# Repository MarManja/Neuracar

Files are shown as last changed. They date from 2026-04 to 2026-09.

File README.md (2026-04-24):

# Neuracar

Este es un proyecto de navegación autónoma basado en ROS 2.

## Estructura
- **neuracar_bringup**: Archivos de lanzamiento y configuración.
- **neuracar_sensors**: Nodos de sensores (IMU, encoder, LiDAR, cámara).
- **neuracar_control**: Nodos de control para tracción, dirección y vehículo.

## Dependencias externas
- **RPLidar A2M12**: LiDAR.
- **Intel RealSense D415**: Cámara.

## Instalación
```bash
git clone https://github.com/tu_usuario/Neuracar.git
cd Neuracar
vcs import src < neuracar.repos
rosdep install --from-paths src --ignore-src -r -y
colcon build
source install/setup.bash

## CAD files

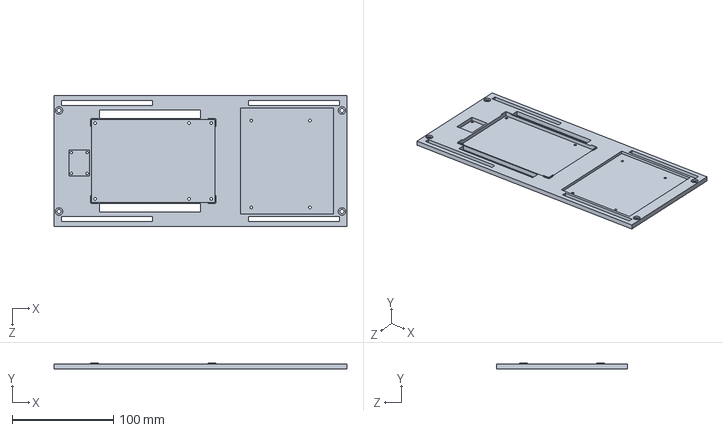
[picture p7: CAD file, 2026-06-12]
mechanical/sldprt/base PLA.SLDPRT
290.0 x 6.00 x 130.0 mm

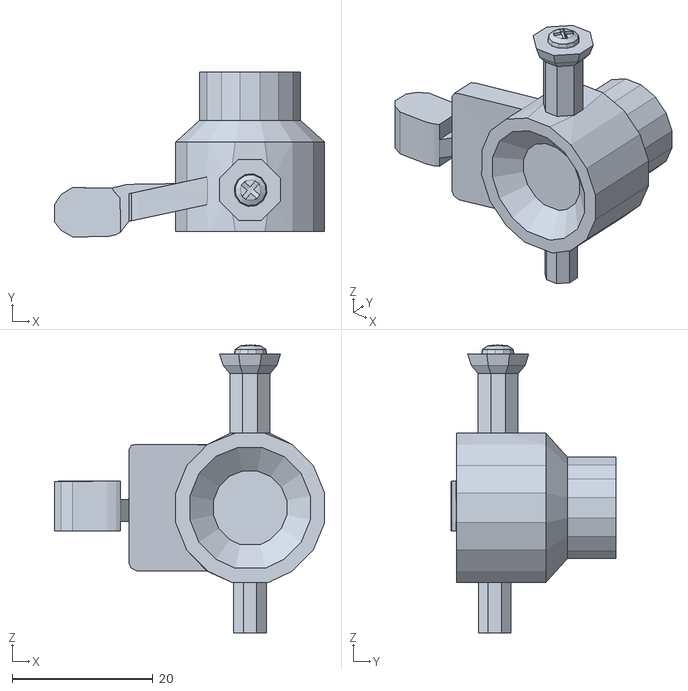
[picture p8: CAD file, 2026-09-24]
src/neuracar_description/meshes/SteeringHubL.stl
38.4 x 23.4 x 40.9

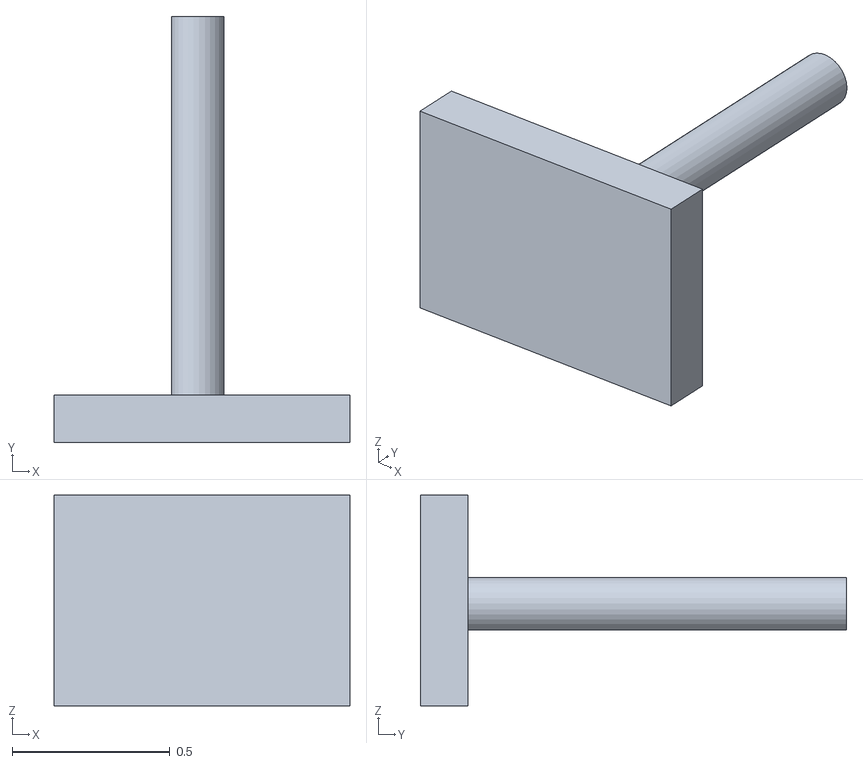
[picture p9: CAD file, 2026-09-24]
src/neuracar_gazebo/models/sign_board_30/meshes/sign_stand.obj
0.937 x 1.35 x 0.668

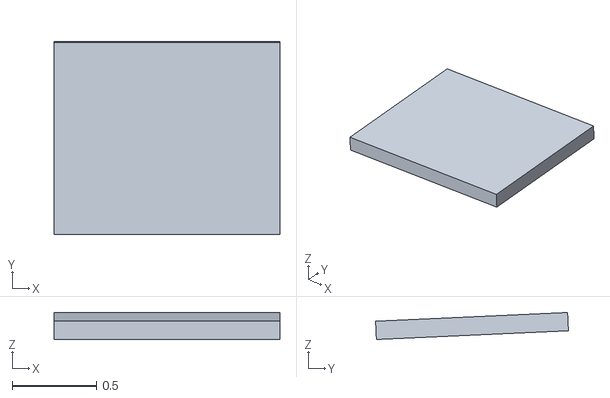
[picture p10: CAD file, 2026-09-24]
src/neuracar_gazebo/models/sign_board_left_turn/meshes/sign_board.obj
1.34 x 1.14 x 0.16

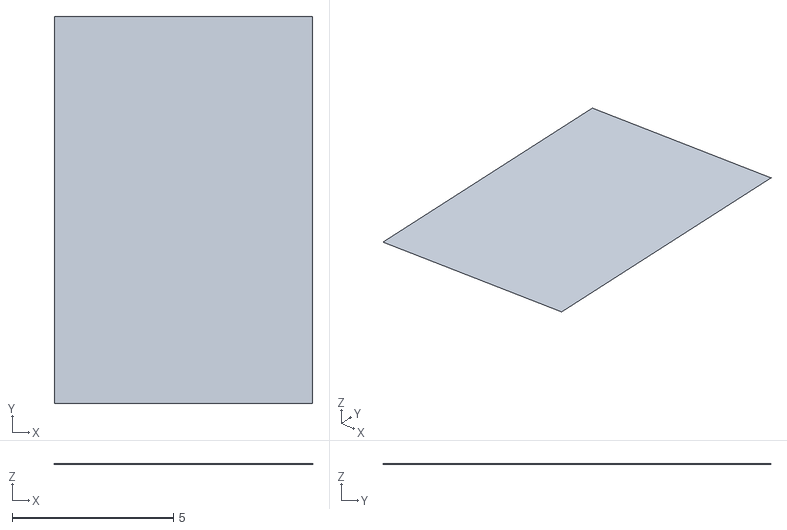
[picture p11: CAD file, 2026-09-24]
src/neuracar_gazebo/models/tmr_track/meshes/automodelcar_tmr.obj
8.00 x 12.0 x 0.002

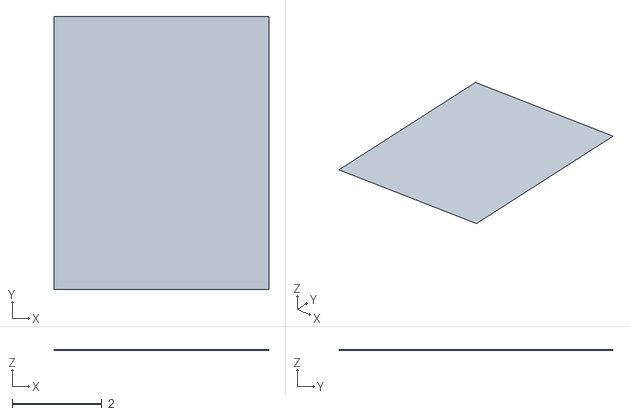
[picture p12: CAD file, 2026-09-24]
src/neuracar_gazebo/models/track/meshes/qcar_track.obj
4.80 x 6.10 x 0.0025

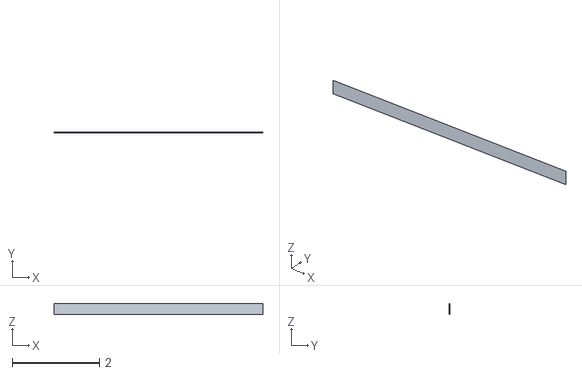
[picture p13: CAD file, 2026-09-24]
src/neuracar_gazebo/models/wall_4_8x0_25/meshes/wood_wall_short.obj
4.80 x 0.0025 x 0.25

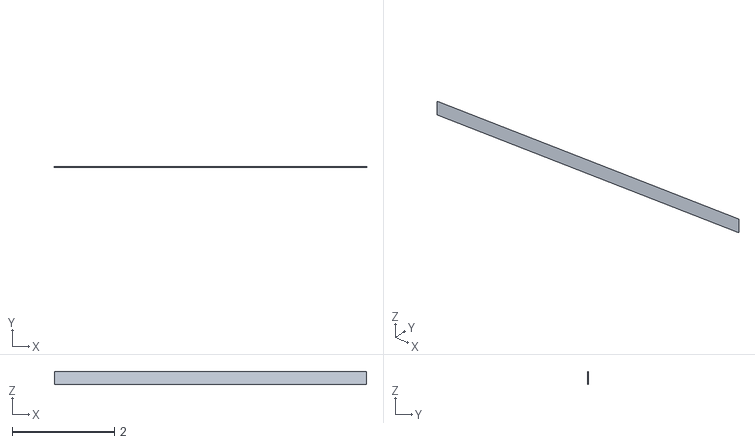
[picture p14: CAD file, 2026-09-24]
src/neuracar_gazebo/models/wall_6_1x0_25/meshes/wood_wall_long.obj
6.10 x 0.0025 x 0.25

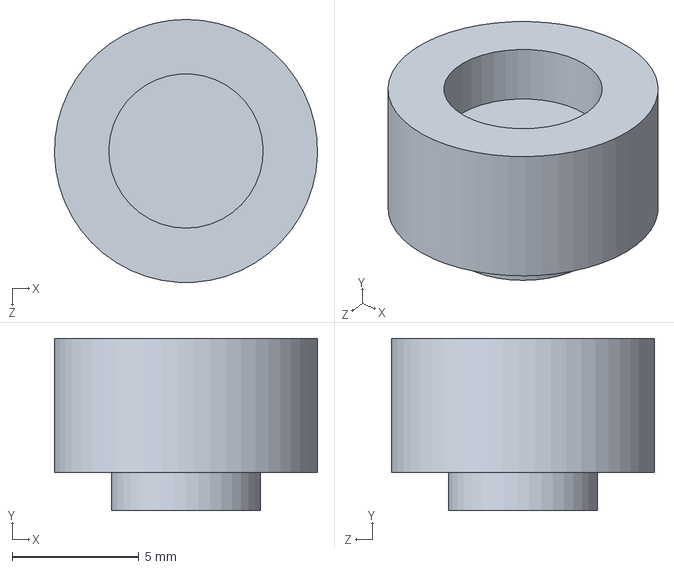
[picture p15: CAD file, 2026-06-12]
mechanical/sldprt/iman.SLDPRT
10.4 x 6.80 x 10.4 mm

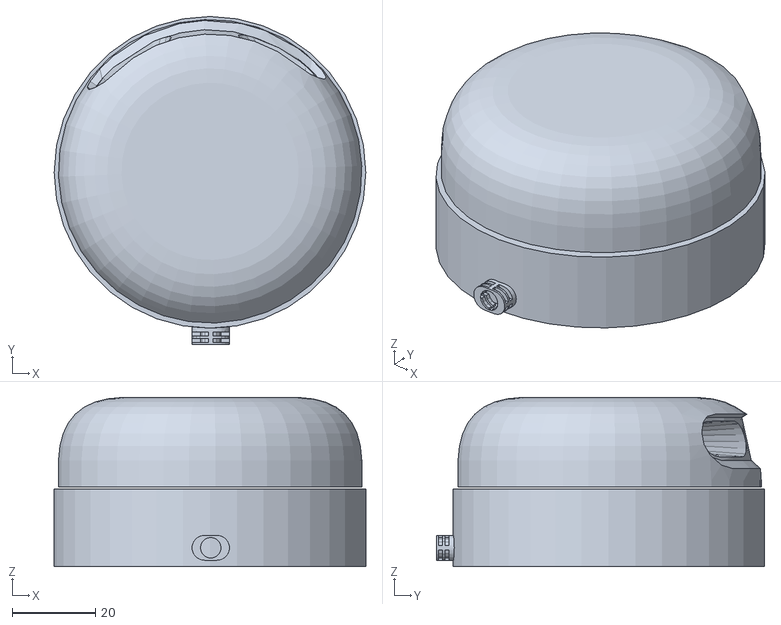
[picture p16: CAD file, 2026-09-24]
src/neuracar_description/meshes/Lidar_A3.stl
75.0 x 78.9 x 40.6

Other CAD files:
src/neuracar_gazebo/models/sign_board_stop/meshes/sign_board.obj
src/neuracar_gazebo/models/sign_board_30/meshes/sign_board.obj
src/neuracar_gazebo/models/sign_board_60/meshes/sign_board.obj
src/neuracar_gazebo/models/sign_board_90/meshes/sign_board.obj
docs/planos/Acrilico.SLDDRW
docs/planos/Soporte Encoder.SLDDRW
docs/planos/Soporte Iman.SLDDRW
docs/planos/inferior.SLDDRW
docs/planos/soporte bateria 2.SLDDRW
docs/planos/soporte bateria.SLDDRW
docs/planos/superior.SLDDRW
mechanical/sldprt/base acrilico.SLDPRT
mechanical/sldprt/bateria Lipo.SLDPRT
mechanical/sldprt/bateria NP-F.SLDPRT
mechanical/sldprt/buck-boost.SLDPRT
mechanical/sldprt/encoder.SLDPRT
mechanical/sldprt/superior.SLDPRT
mechanical/stl/base PLA.STL
mechanical/stl/base acrilico.STL
mechanical/stl/bateria Lipo.STL
mechanical/stl/bateria NP -F.STL
mechanical/stl/buck - boost.STL
mechanical/stl/superior.STL
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

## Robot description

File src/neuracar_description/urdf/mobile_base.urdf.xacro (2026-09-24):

<?xml version="1.0"?>

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
<robot name="Neuracar" xmlns:xacro="http://www.ros.org/wiki/xacro">
  <xacro:macro name="Neuracar" params="parent prefix *origin">
    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
    <xacro:include filename="$(find neuracar_description)/urdf/common_properties.xacro" />

    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
    <xacro:property name="degrees_30" value="0.523599"/>
    <xacro:property name="degrees_45" value="0.785398163"/>
    <xacro:property name="degrees_90" value="1.57079633"/>

    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
    <xacro:property name="chassis_length" value="0.425"/>
    <xacro:property name="chassis_width" value="0.192"/>
    <xacro:property name="chassis_height" value="0.182"/>
    <xacro:property name="chassis_mass" value="2.552"/>

  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
    <xacro:property name="hub_dia" value="0.015"/>
    <xacro:property name="tire_dia" value="0.053"/>
    <xacro:property name="tire_width" value="0.025"/>
    <xacro:property name="hex_hub_depth" value="0.018"/>
    <xacro:property name="wheel_mass" value="0.035"/>
  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
    <xacro:property name="wheelbase" value="0.265"/>
    <xacro:property name="hex_hub_dist" value="0.285"/>
    <xacro:property name="axle_length" value="0.025"/>
    <xacro:property name="axle_eff_limit" value="5.12766"/>
    <xacro:property name="axle_vel_limit" value="244.8696"/>
    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
    <xacro:property name="servo_stall_torque" value="0.5649"/>
    <xacro:property name="servo_no_load_speed" value="4.553"/>

    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
    <xacro:property name="ctrl_period" value="0.01"/>


    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
    <xacro:macro name="null_inertial">
      <inertial>
        <origin rpy="0 0 0" xyz="0 0 0"/>
        <mass value="0.001"/>
        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
      </inertial>
    </xacro:macro>

    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
    <xacro:macro name="solid_cuboid_inertial" params="width depth height mass *origin">
      <inertial>
        <xacro:insert_block name="origin"/>
        <mass value="${mass}"/>
        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
      </inertial>
    </xacro:macro>

    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
    <xacro:macro name="thick_walled_tube_inertial" params="inner_rad outer_rad height mass">
      <inertial>
        <mass value="${mass}"/>
        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
      </inertial>
    </xacro:macro>

    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

   <link name="base_footprint" />

    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
    <link name="base_link">
      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

      <xacro:solid_cuboid_inertial width="${chassis_length}" depth="${chassis_width}" height="${chassis_height}" mass="${chassis_mass}">
        <origin xyz="0 0 0"/>
      </xacro:solid_cuboid_inertial>
      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

    </link>

  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
    <joint name="base_footprint_to_chasis" type="fixed">
      <parent link="base_footprint"/>
      <child link="base_link"/>
    </joint>

    <joint name="body_lidar_joint" type="fixed">
      <parent link="base_link"/>
      <child link="lidar_base"/>
      <origin rpy="0 0 0" xyz="0.0227 -0.00145 0.14352"/>
      <axis xyz="0 0 1"/>
      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
    </joint>
    <link name="lidar_base">
        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
        <inertial>
          <origin rpy="0 0 0" xyz="0 0 0"/>
          <mass value="0.1"/>
          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
        </inertial>
    </link>
    <link name="lidar"/>
    <joint name="lidar_base_to_optics_joint" type="fixed">
      <parent link="lidar_base"/>
      <child link="lidar"/>
      <origin xyz="0.0 0.0 0.031" rpy="0.0 0.0 0.0"/>
    </joint>

    <joint name="camera_rgb_joint" type="fixed">
      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
      <origin rpy="0 0.192 0" xyz="0.0914 -0.0015 0.14622"/>
      <parent link="base_link"/>
      <child link="camera_rgb"/>
    </joint>
    <link name="camera_rgb">
      <inertial>
        <mass value="0.0615752"/>
        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
      </inertial>
      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
    </link>

    <joint name="imu_joint" type="fixed">
        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
         <origin rpy="0 0 ${-pi/2.0}" xyz="0.1355 0.0015 0.094"/>
        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
        <parent link="base_link"/>
        <child link="imu"/>
    </joint>
    <link name="imu">
      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
      <xacro:box_inertia m="0.0025" l="0.0257" w="0.0205" h="0.0025" xyz="0 0 0" rpy="0 0 0"/>
    </link>

    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
    
    <joint name="left_front_position_joint" type="fixed">
      <parent link="base_link"/>
      <child link="left_steering_link"/>
      <origin rpy="0 0 0" xyz="0.12960 0.05590 0.03338"/>
      <axis xyz="0 0 1" />
    </joint>

    <link name="left_steering_link">
      <xacro:null_inertial/>
      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
    </link>
    
    <joint name="left_steering_joint" type="revolute">
      <parent link="left_steering_link"/>
      <child link="left_front_axle_carrier"/>
      <axis xyz = "0 0 1"/>
      <limit lower="-0.523599" upper="0.523599" effort="0.5649" velocity="4.553"/>
      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
    </joint>
    
    <link name="left_front_axle_carrier">
      <xacro:null_inertial/>
    </link>
    
    <joint name="left_front_axle" type="continuous">
      <parent link="left_front_axle_carrier"/>
      <child link="left_front_wheel"/>
      <axis xyz="0 -1 0"/>
      <origin rpy="0 0 3.14159"/>
      <limit effort="5.12766" velocity="244.8696"/>
      <dynamics damping="0.1" friction="0.1"/>
      <mimic joint="left_rear_axle" multiplier="1.0" offset="0"/>
    </joint>
    
    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
    <link name="left_front_wheel">
      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
      <xacro:thick_walled_tube_inertial inner_rad="${hub_dia / 2}" outer_rad="${tire_dia / 2}" height="${tire_width}" mass="${wheel_mass}"/>
    </link>

    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

    <link name="right_front_axle_carrier">
      <xacro:null_inertial/>
    </link>
    <joint name="right_front_axle" type="continuous">
      <parent link="right_front_axle_carrier"/>
      <child link="right_front_wheel"/>
      <axis xyz="0 1 0"/>
      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
      <limit effort="5.12766" velocity="244.8696"/>
      <dynamics damping="0.1" friction="0.1"/>
      <mimic joint="right_rear_axle" multiplier="1.0" offset="0"/>
    </joint>
    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
    <link name="right_front_wheel">
      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
      <xacro:thick_walled_tube_inertial inner_rad="${hub_dia / 2}" outer_rad="${tire_dia / 2}" height="${tire_width}" mass="${wheel_mass}"/>
    </link>

    <joint name="right_front_position_joint" type="fixed">
      <parent link="base_link"/>
      <child link="right_steering_link"/>
      <origin rpy="0 0 0" xyz="0.12960 -0.05590 0.03338"/>
    </joint>

    <link name="right_steering_link">
      <xacro:null_inertial/>
      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
    </link>

    <joint name="right_steering_joint" type="revolute">
      <parent link="right_steering_link"/>
      <child link="right_front_axle_carrier"/>
      <axis xyz = "0 0 1"/>
      <limit lower="-0.523599" upper="0.523599" effort="0.5649" velocity="4.553"/>
      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
    </joint>

    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
    <link name="left_rear_axle_carrier">
      <xacro:null_inertial/>
    </link>
    <joint name="left_rear_axle" type="continuous">
      <parent link="left_rear_axle_carrier"/>
      <child link="left_rear_wheel"/>
      <axis xyz="0 -1 0"/>
      <origin rpy="0 0 3.14159"/>
      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
      <dynamics damping="0.1" friction="0.1"/>
    </joint>
    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
    <link name="left_rear_wheel">
      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
      <xacro:thick_walled_tube_inertial inner_rad="${hub_dia / 2}" outer_rad="${tire_dia / 2}" height="${tire_width}" mass="${wheel_mass}"/>
    </link>

    <joint name="left_rear_position_joint" type="fixed">
      <parent link="base_link"/>
      <child link="left_rear_axle_carrier"/>
      <origin rpy="0 0 0" xyz="-0.12765 0.05610 0.03338"/>
    </joint>

  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

    <link name="right_rear_axle_carrier">
      <xacro:null_inertial/>
    </link>
    <joint name="right_rear_axle" type="continuous">
      <parent link="right_rear_axle_carrier"/>
      <child link="right_rear_wheel"/>
      <axis xyz="0 1 0"/>
      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
      <dynamics damping="0.1" friction="0.1"/>
    </joint>
    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
    <link name="right_rear_wheel">
      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
      <xacro:thick_walled_tube_inertial inner_rad="${hub_dia / 2}" outer_rad="${tire_dia / 2}" height="${tire_width}" mass="${wheel_mass}"/>
    </link>

    <joint name="right_rear_position_joint" type="fixed">
      <parent link="base_link"/>
      <child link="right_rear_axle_carrier"/>
      <origin rpy="0 0 0" xyz="-0.12765 -0.05610 0.03338"/>
    </joint>

    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
  
  </xacro:macro>

</robot>

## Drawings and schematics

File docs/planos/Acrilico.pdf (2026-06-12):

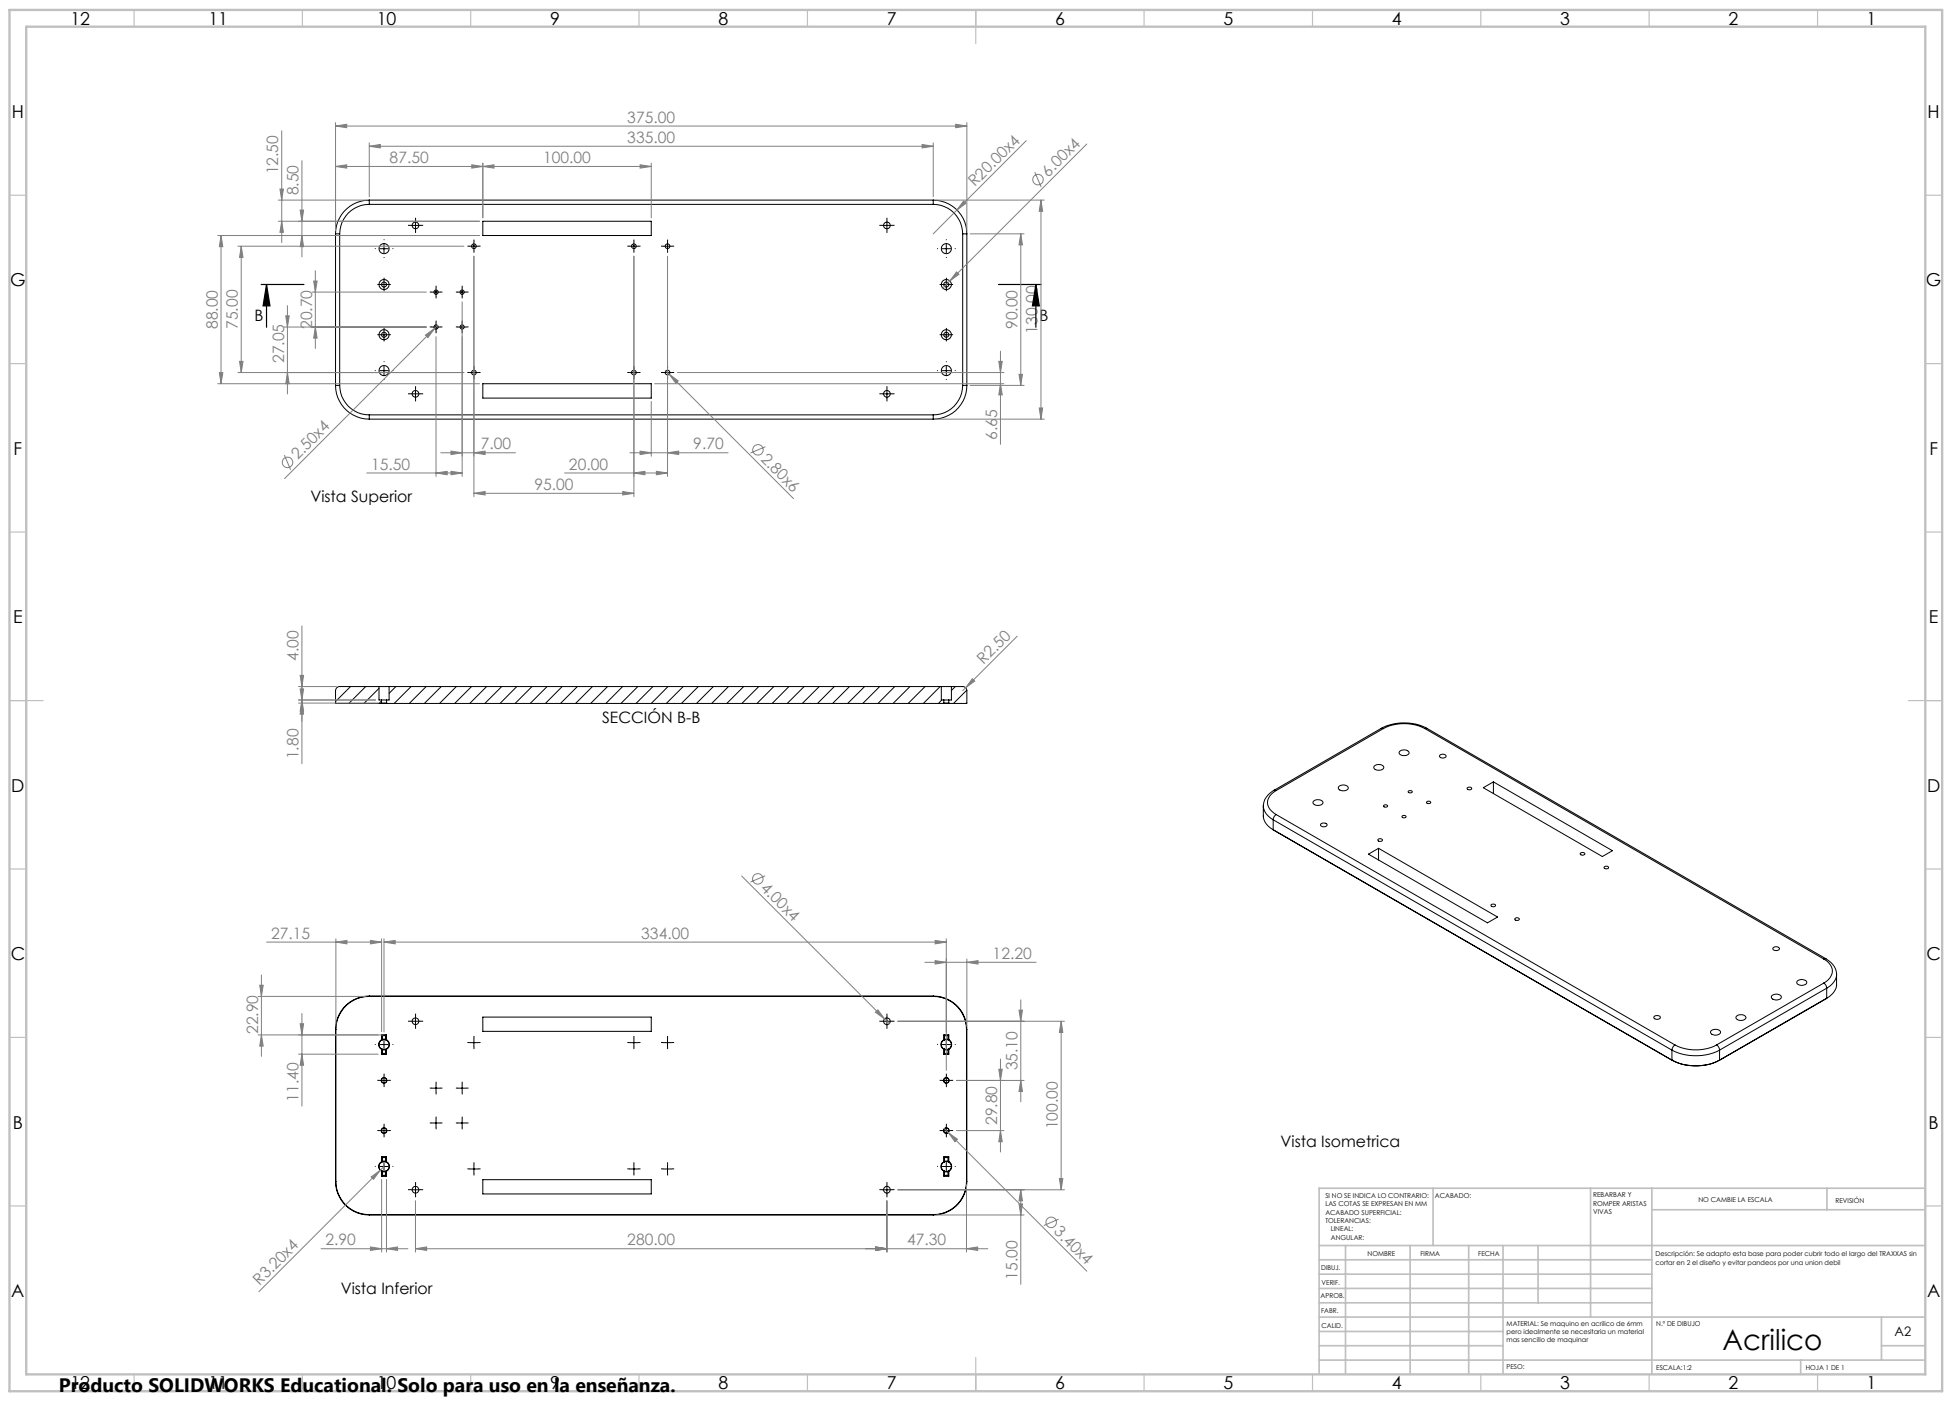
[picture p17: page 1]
Vista Superior; SECCIÓN B-B; Vista Inferior; Vista Isometrica; ACABADO:; REBARBAR Y; ROMPER ARISTAS; NO CAMBIE LA ESCALA; REVISIÓN; ESCALA:1:2; HOJA 1 DE 1

SI NO SE INDICA LO CONTRARIO:
LAS COTAS SE EXPRESAN EN MM
ACABADO SUPERFICIAL:
TOLERANCIAS:
LINEAL:
ANGULAR:

NOMBRE | FIRMA | FECHA | | | | Descripción: Se adapto esta base para poder cubrir todo el largo del TRAXXAS sin cortar en 2 el diseño y evitar pandeos por una union debil

DIBUJ.
VERIF.
APROB.
FABR.
CALID. | | | | MATERIAL: Se maquino en acrilico de 6mm pero idealmente se necesitaria un material mas sencillo de maquinar | N.º DE DIBUJO Acrilico | A2

Producto SOLIDWORKS Educational. Solo para uso en la enseñanza.

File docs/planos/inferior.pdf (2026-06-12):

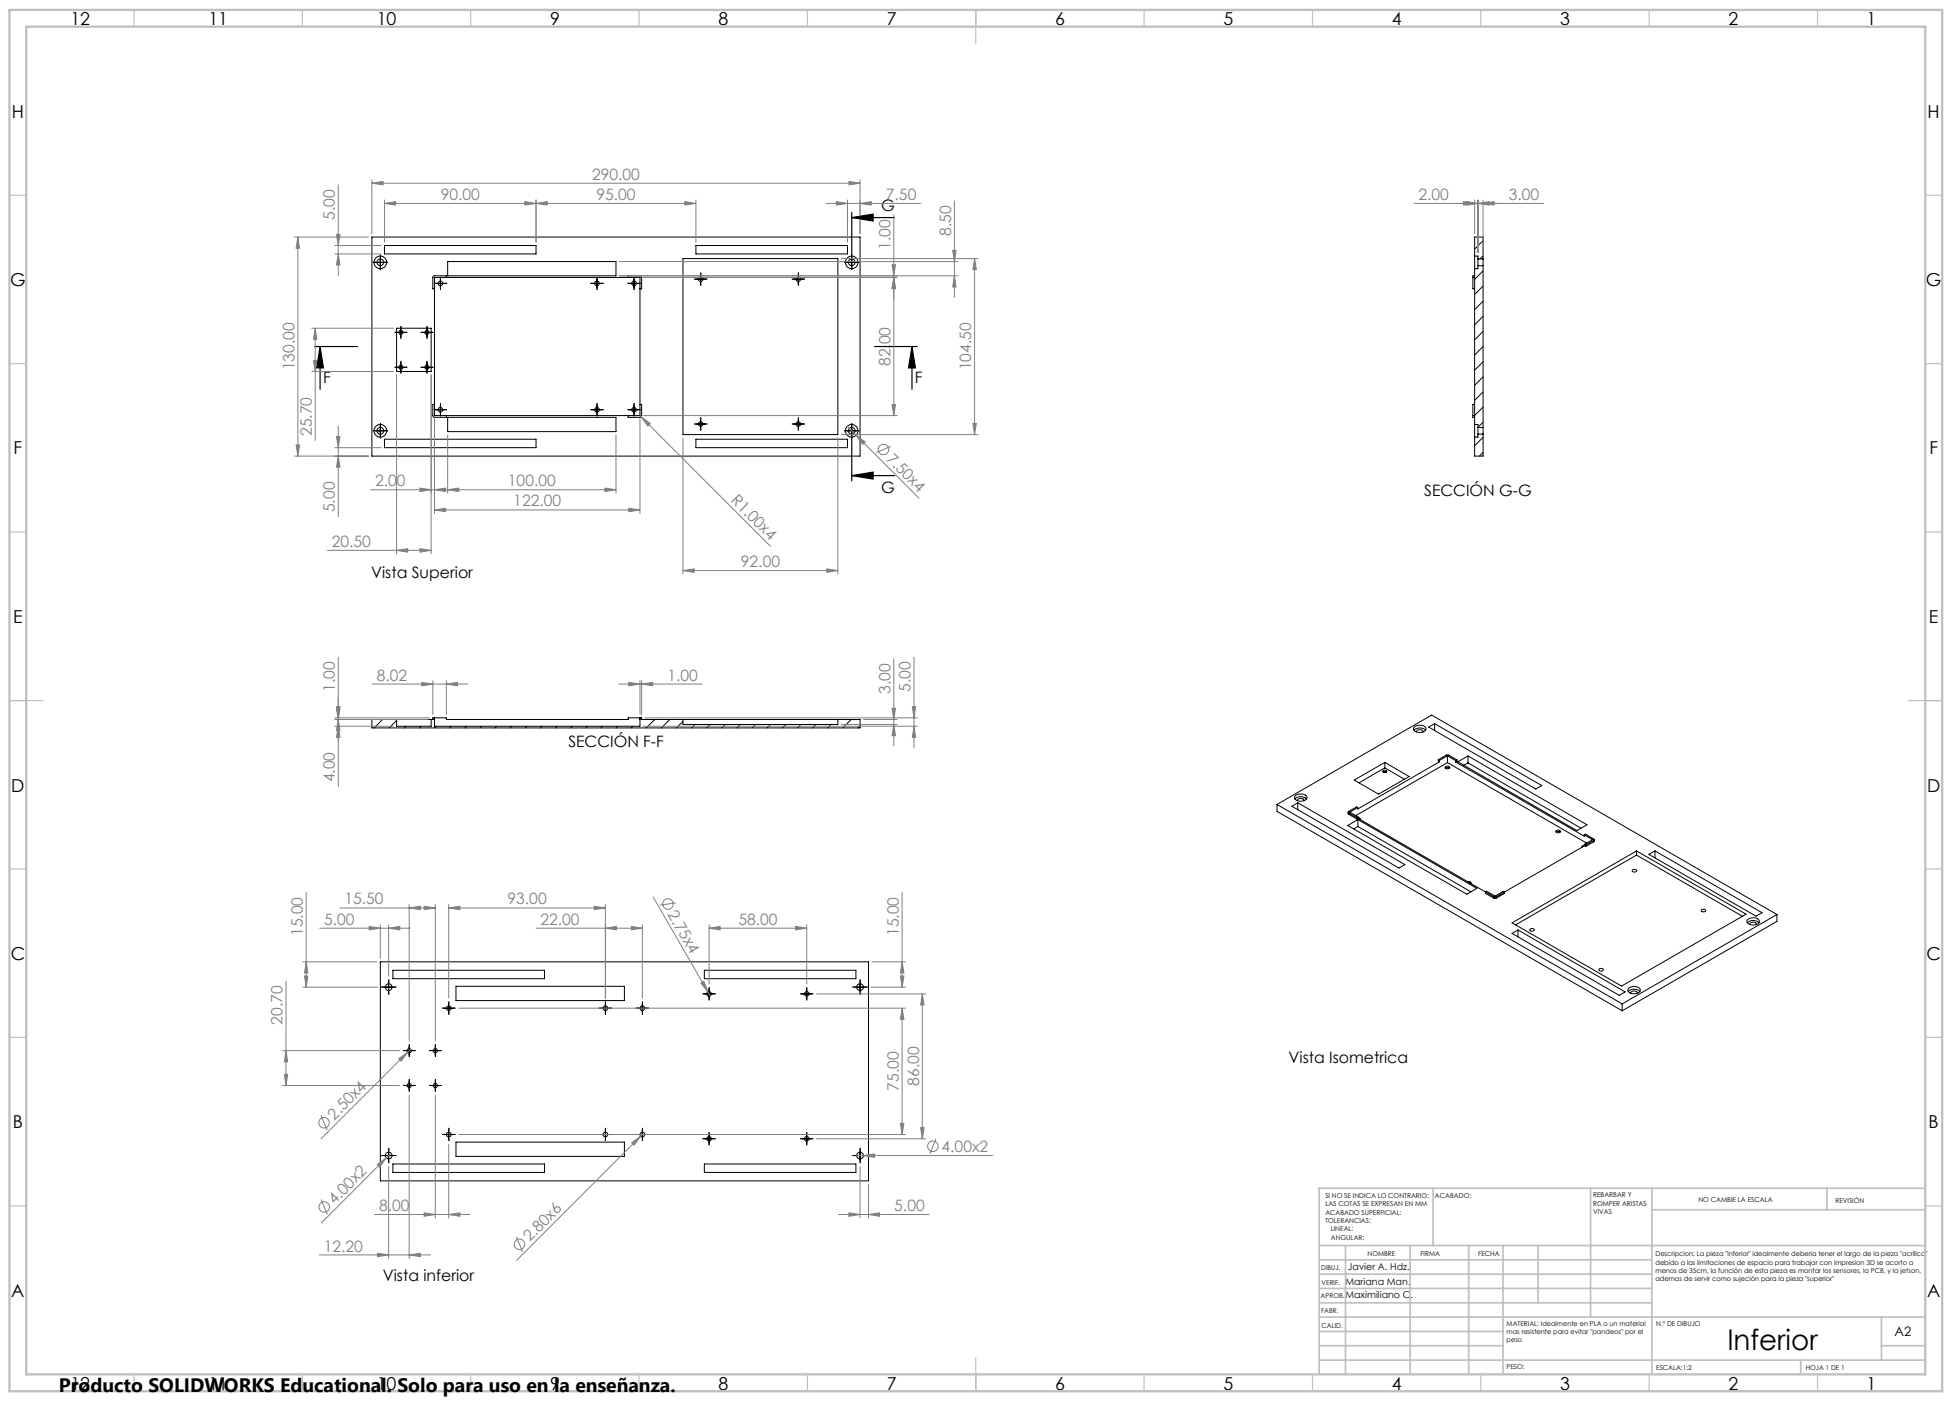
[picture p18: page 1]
Vista Superior; Vista inferior; Vista Isometrica; SECCIÓN F-F; SECCIÓN G-G; ACABADO:; REBARBAR Y; ROMPER ARISTAS; NO CAMBIE LA ESCALA; REVISIÓN; ESCALA:1:2; HOJA 1 DE 1

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

NOMBRE | FIRMA | FECHA | | | | Descripcion: La pieza "inferior" idealmente deberia tener el largo de la pieza "acrilico" debido a las limitaciones de espacio para trabajar con impresion 3D se acorto a menos de 35cm, la función de esta pieza es montar los sensores, la PCB, y la jetson, ademas de servir como sujeción para la pieza "superior"

DIBUJ. | Javier A. Hdz.
VERIF. | Mariana Man.
APROB. | Maximiliano C.

FABR.
CALID. | | | | MATERIAL: Idealmente en PLA o un material mas resistente para evitar "pandeos" por el peso | N.º DE DIBUJO Inferior | A2

Producto SOLIDWORKS Educational. Solo para uso en la enseñanza.

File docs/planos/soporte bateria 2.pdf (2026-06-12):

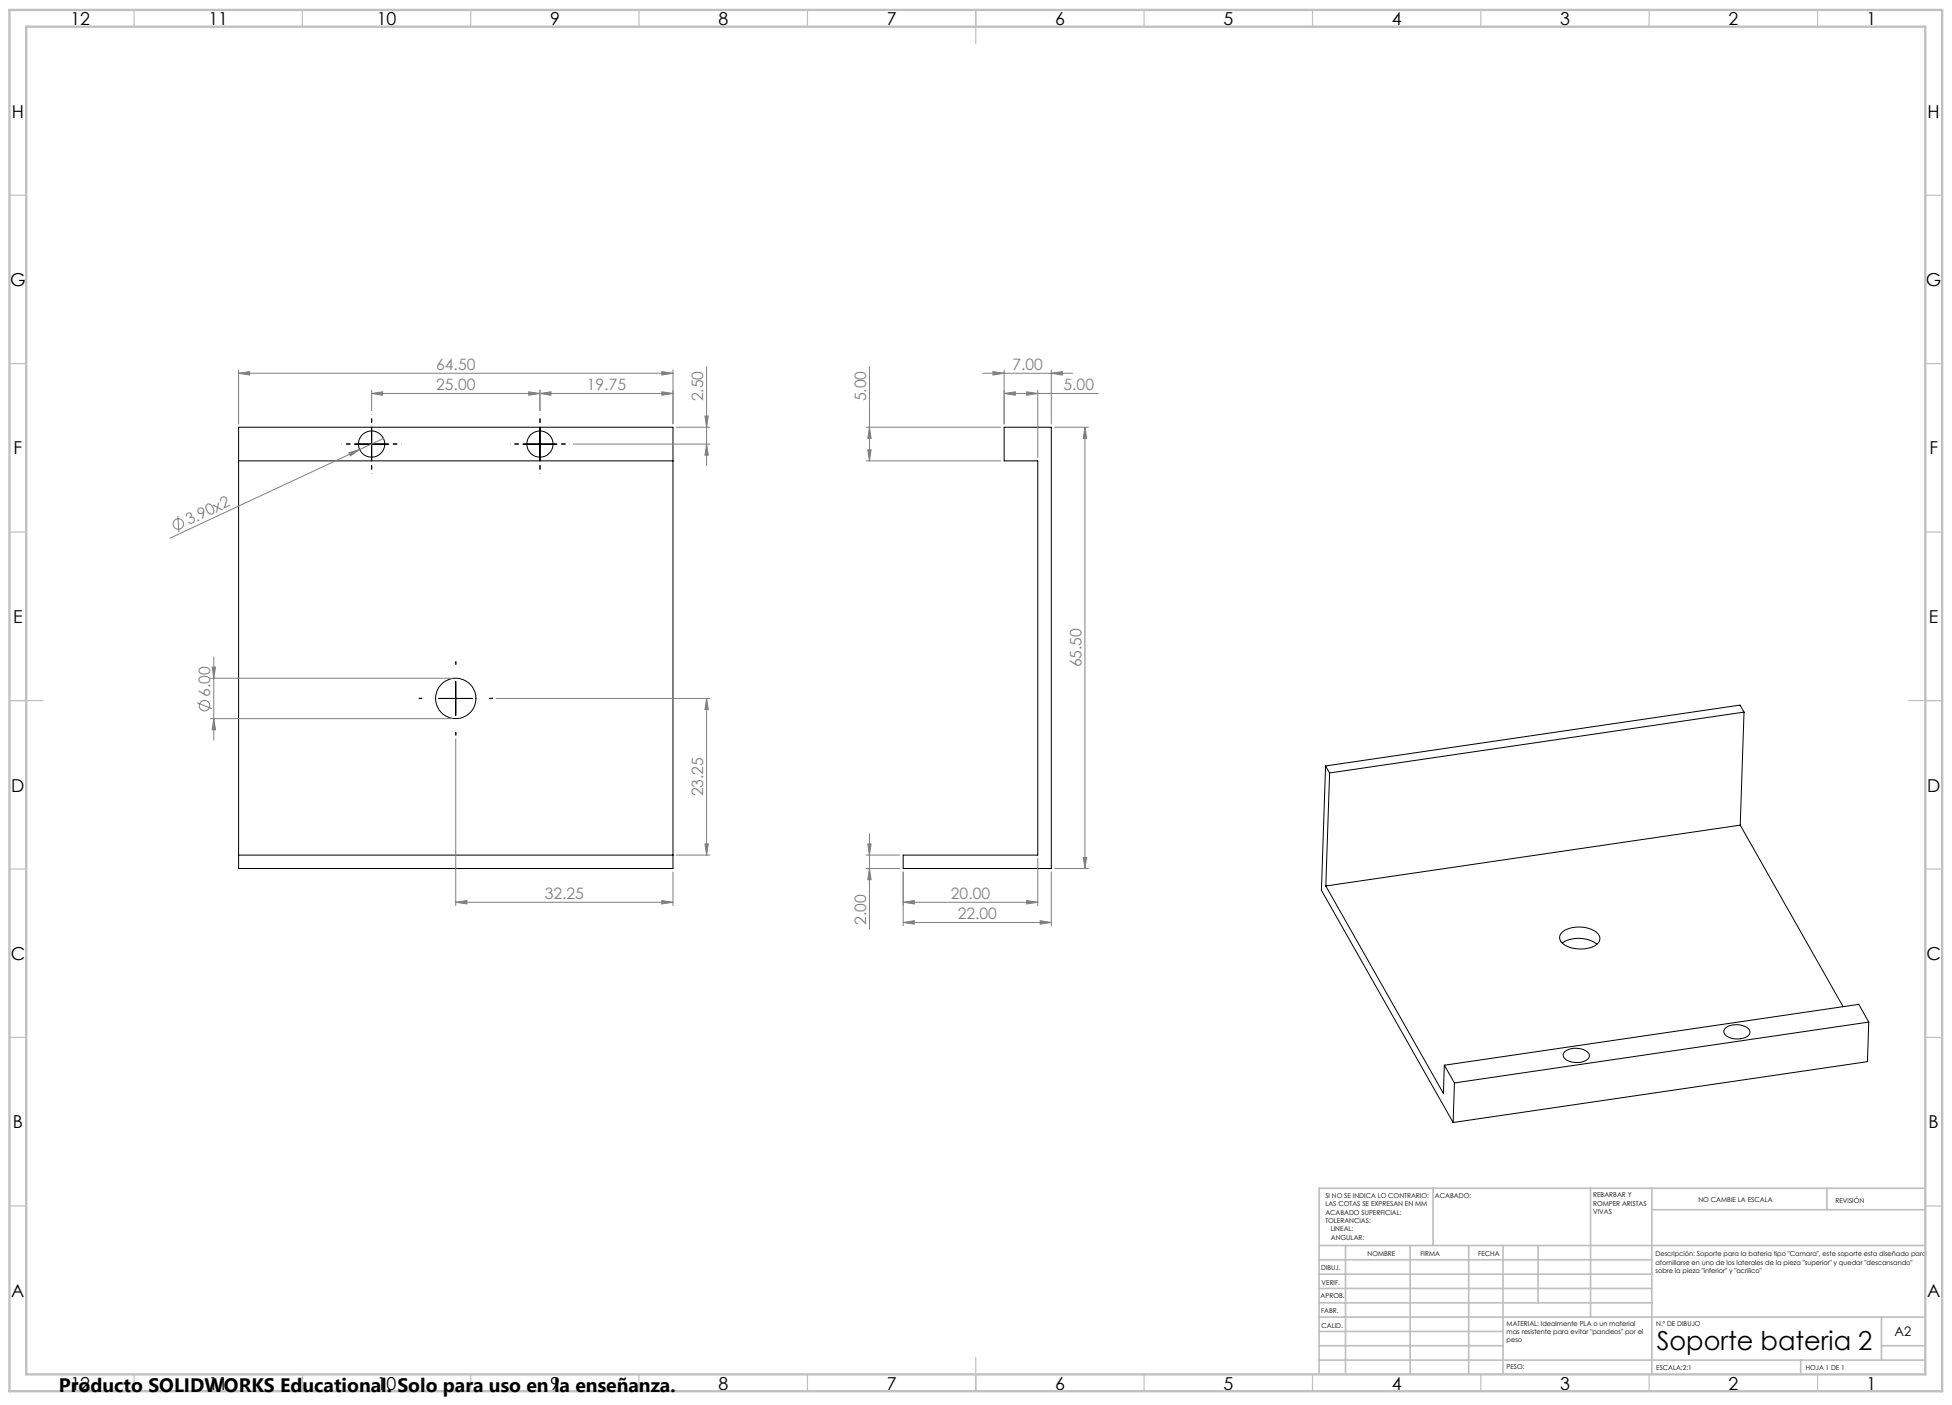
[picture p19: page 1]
ESCALA:2:1; HOJA 1 DE 1

SI NO SE INDICA LO CONTRARIO: LAS COTAS SE EXPRESAN EN MM ACABADO SUPERFICIAL: TOLERANCIAS: LINEAL: ANGULAR: | ACABADO: | REBARBAR Y ROMPER ARISTAS VIVAS | NO CAMBIE LA ESCALA | REVISIÓN

NOMBRE | FIRMA | FECHA | | | | Descripción: Soporte para la bateria tipo "Camara", este soporte esta diseñado para atornillarse en uno de los laterales de la pieza "superior" y quedar "descansando" sobre la pieza "inferior" y "acrilico"

DIBUJ.
VERIF.
APROB.
FABR.
CALID. | | | | MATERIAL: Idealmente PLA o un material mas resistente para evitar "pandeos" por el peso | N.º DE DIBUJO Soporte bateria 2 | A2

Producto SOLIDWORKS Educational. Solo para uso en la enseñanza.

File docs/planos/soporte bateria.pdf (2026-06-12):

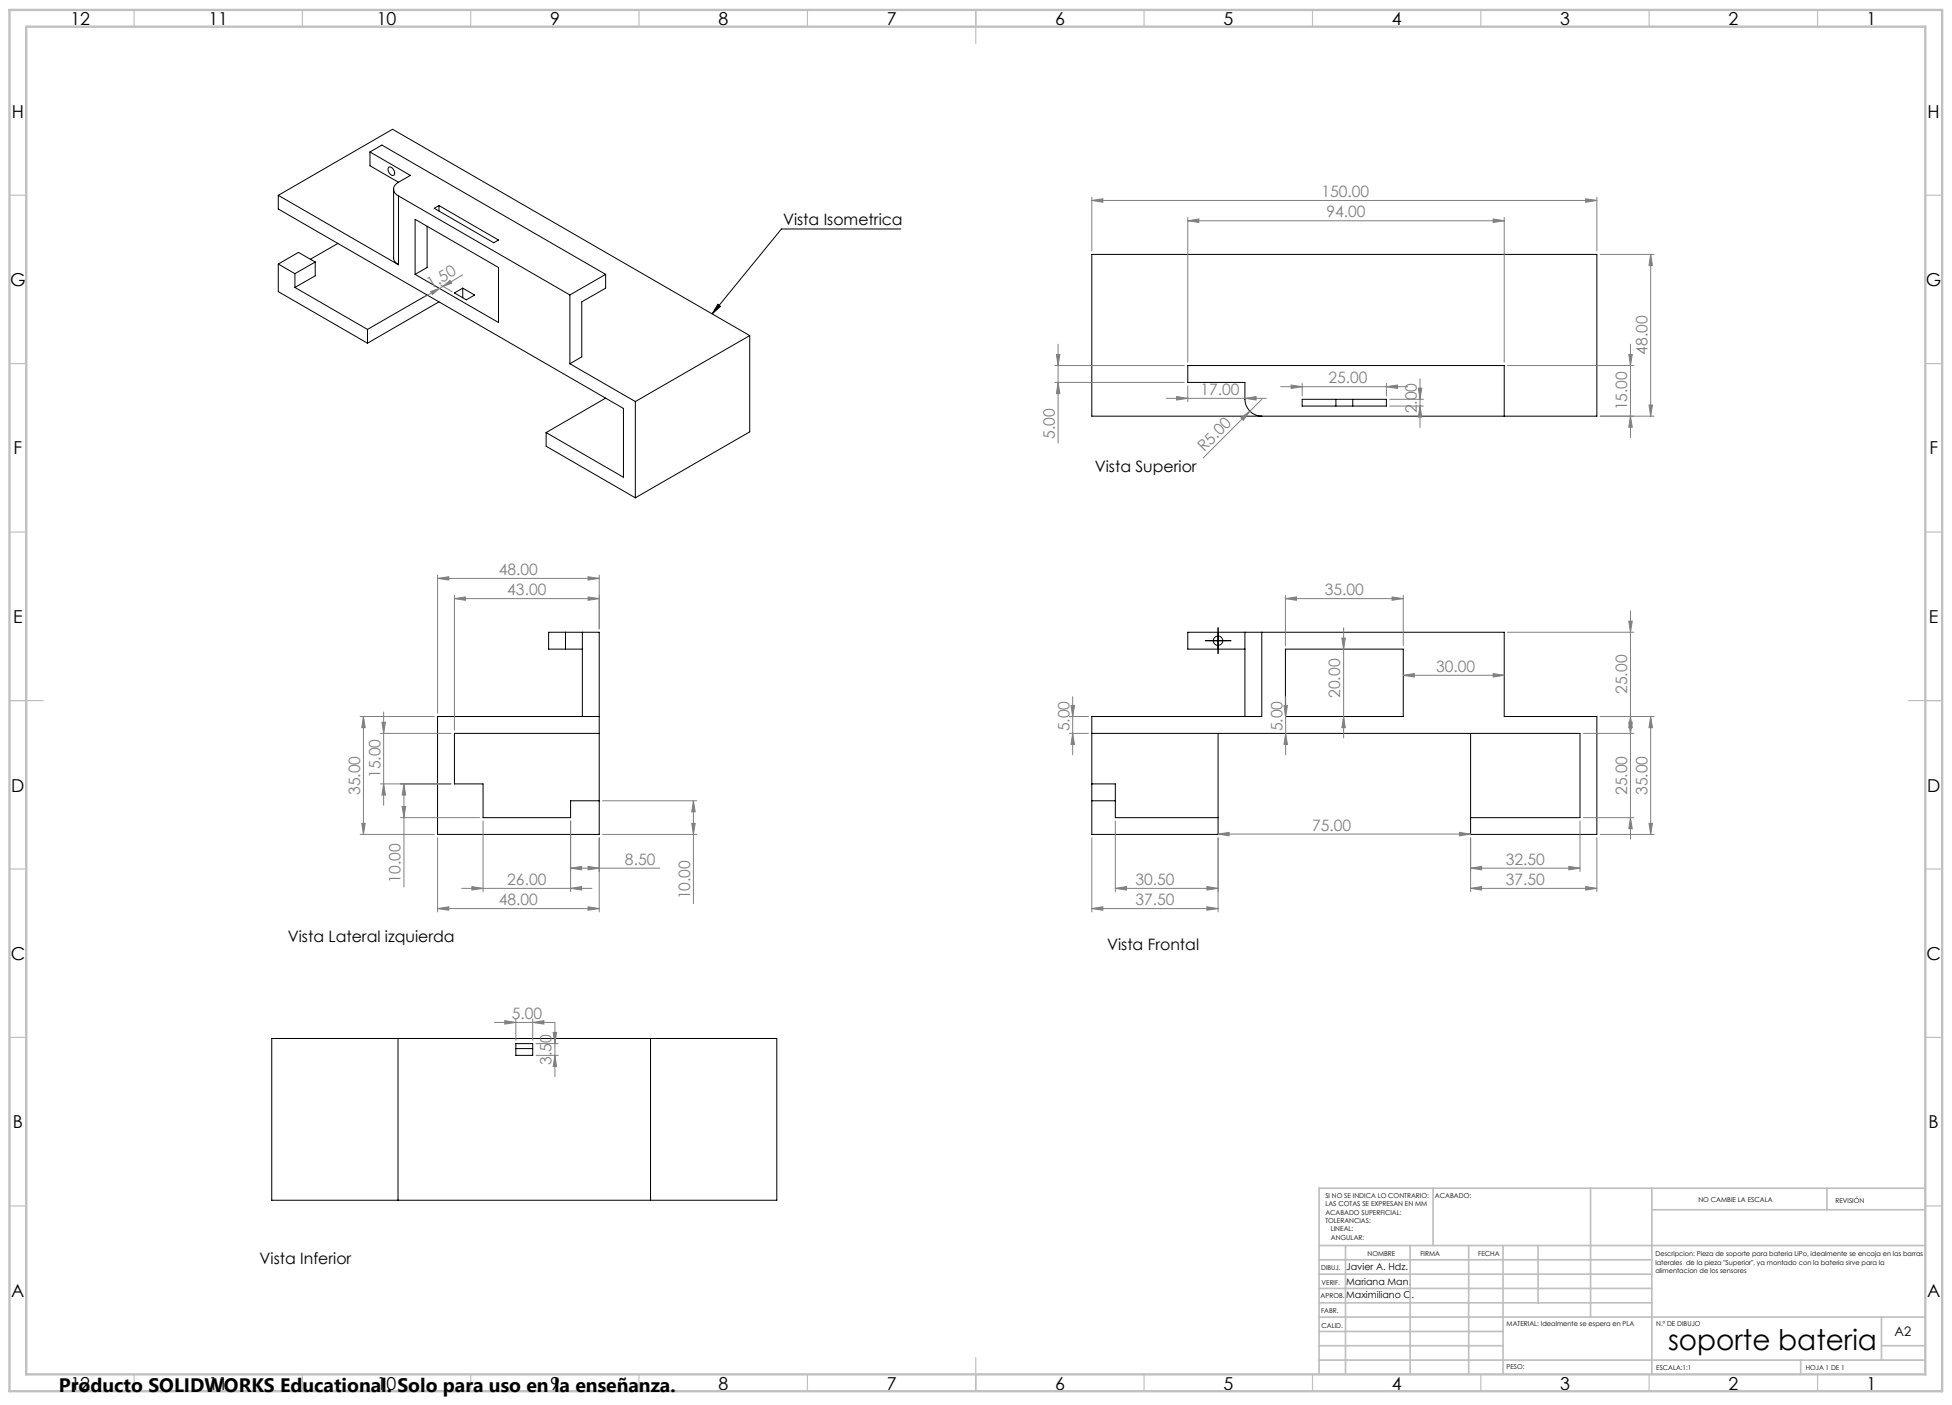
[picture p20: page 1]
Vista Isometrica; Vista Inferior; Vista Superior; Vista Frontal; NO CAMBIE LA ESCALA; REVISIÓN; ESCALA:1:1; HOJA 1 DE 1

Vista Lateral izquierda

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

NOMBRE | FIRMA | FECHA | | | | Descripcion: Pieza de soporte para bateria LiPo, idealmente se encaja en las barras laterales de la pieza "Superior", ya montado con la bateria sirve para la alimentacion de los sensores

DIBUJ. | Javier A. Hdz.
VERIF. | Mariana Man.
APROB. | Maximiliano C.

FABR.
CALID. | | | | MATERIAL: Idealmente se espera en PLA | N.º DE DIBUJO soporte bateria | A2

Producto SOLIDWORKS Educational. Solo para uso en la enseñanza.

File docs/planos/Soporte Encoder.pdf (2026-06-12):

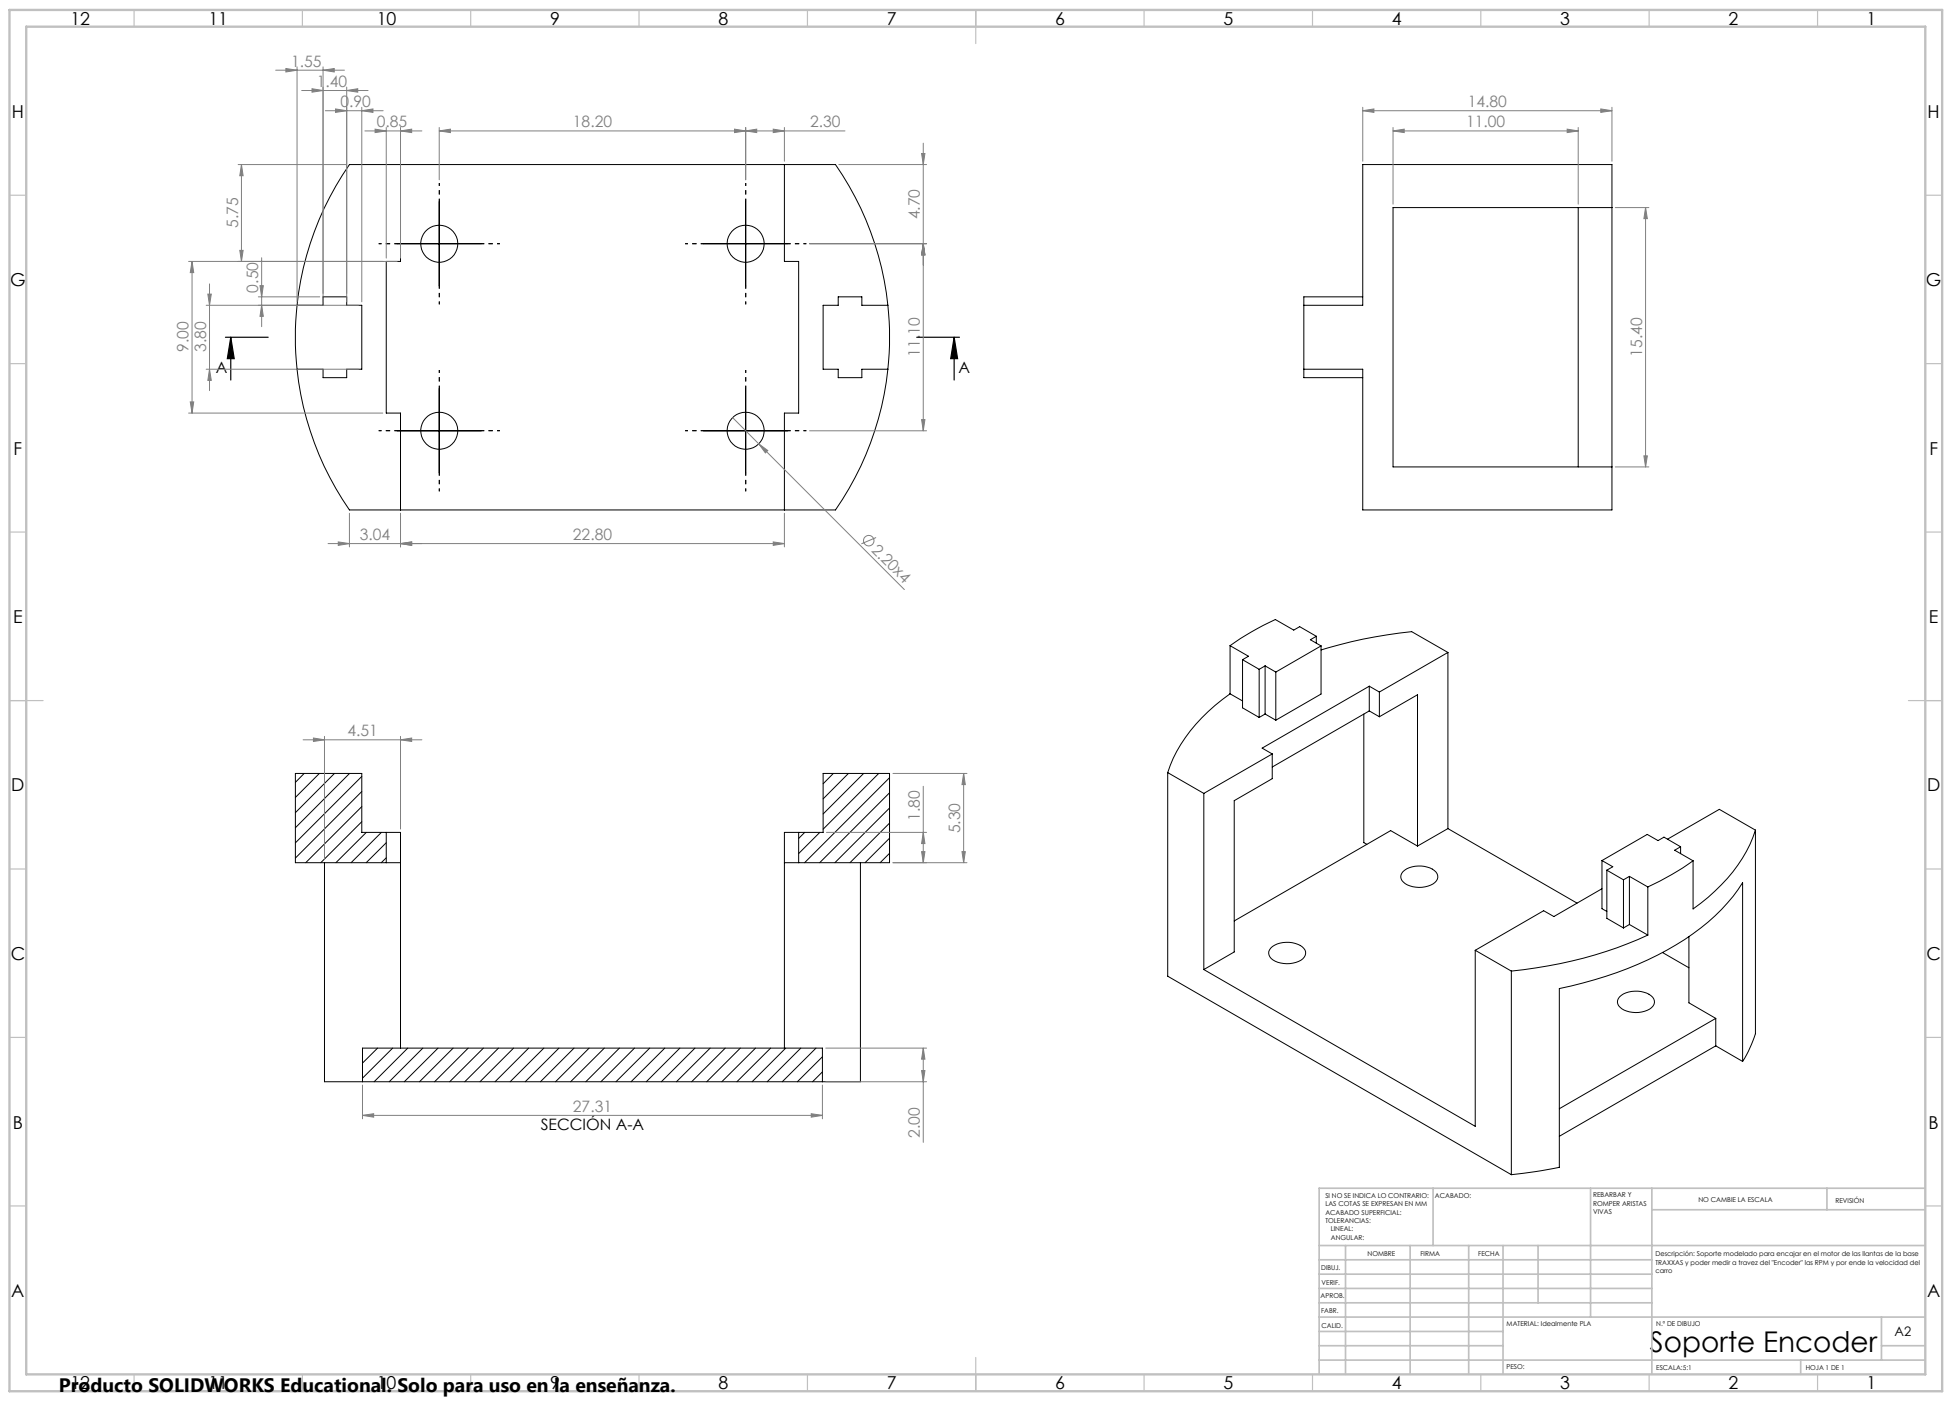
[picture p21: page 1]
SECCIÓN A-A; ACABADO:; REBARBAR Y; ROMPER ARISTAS; NO CAMBIE LA ESCALA; REVISIÓN; ESCALA:5:1; HOJA 1 DE 1

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

NOMBRE | FIRMA | FECHA | | | | Descripción: Soporte modelado para encajar en el motor de las llantas de la base TRAXXAS y poder medir a travez del "Encoder" las RPM y por ende la velocidad del carro

DIBUJ.
VERIF.
APROB.
FABR.
CALID. | | | | MATERIAL: Idealmente PLA | N.º DE DIBUJO Soporte Encoder | A2

Producto SOLIDWORKS Educational. Solo para uso en la enseñanza.

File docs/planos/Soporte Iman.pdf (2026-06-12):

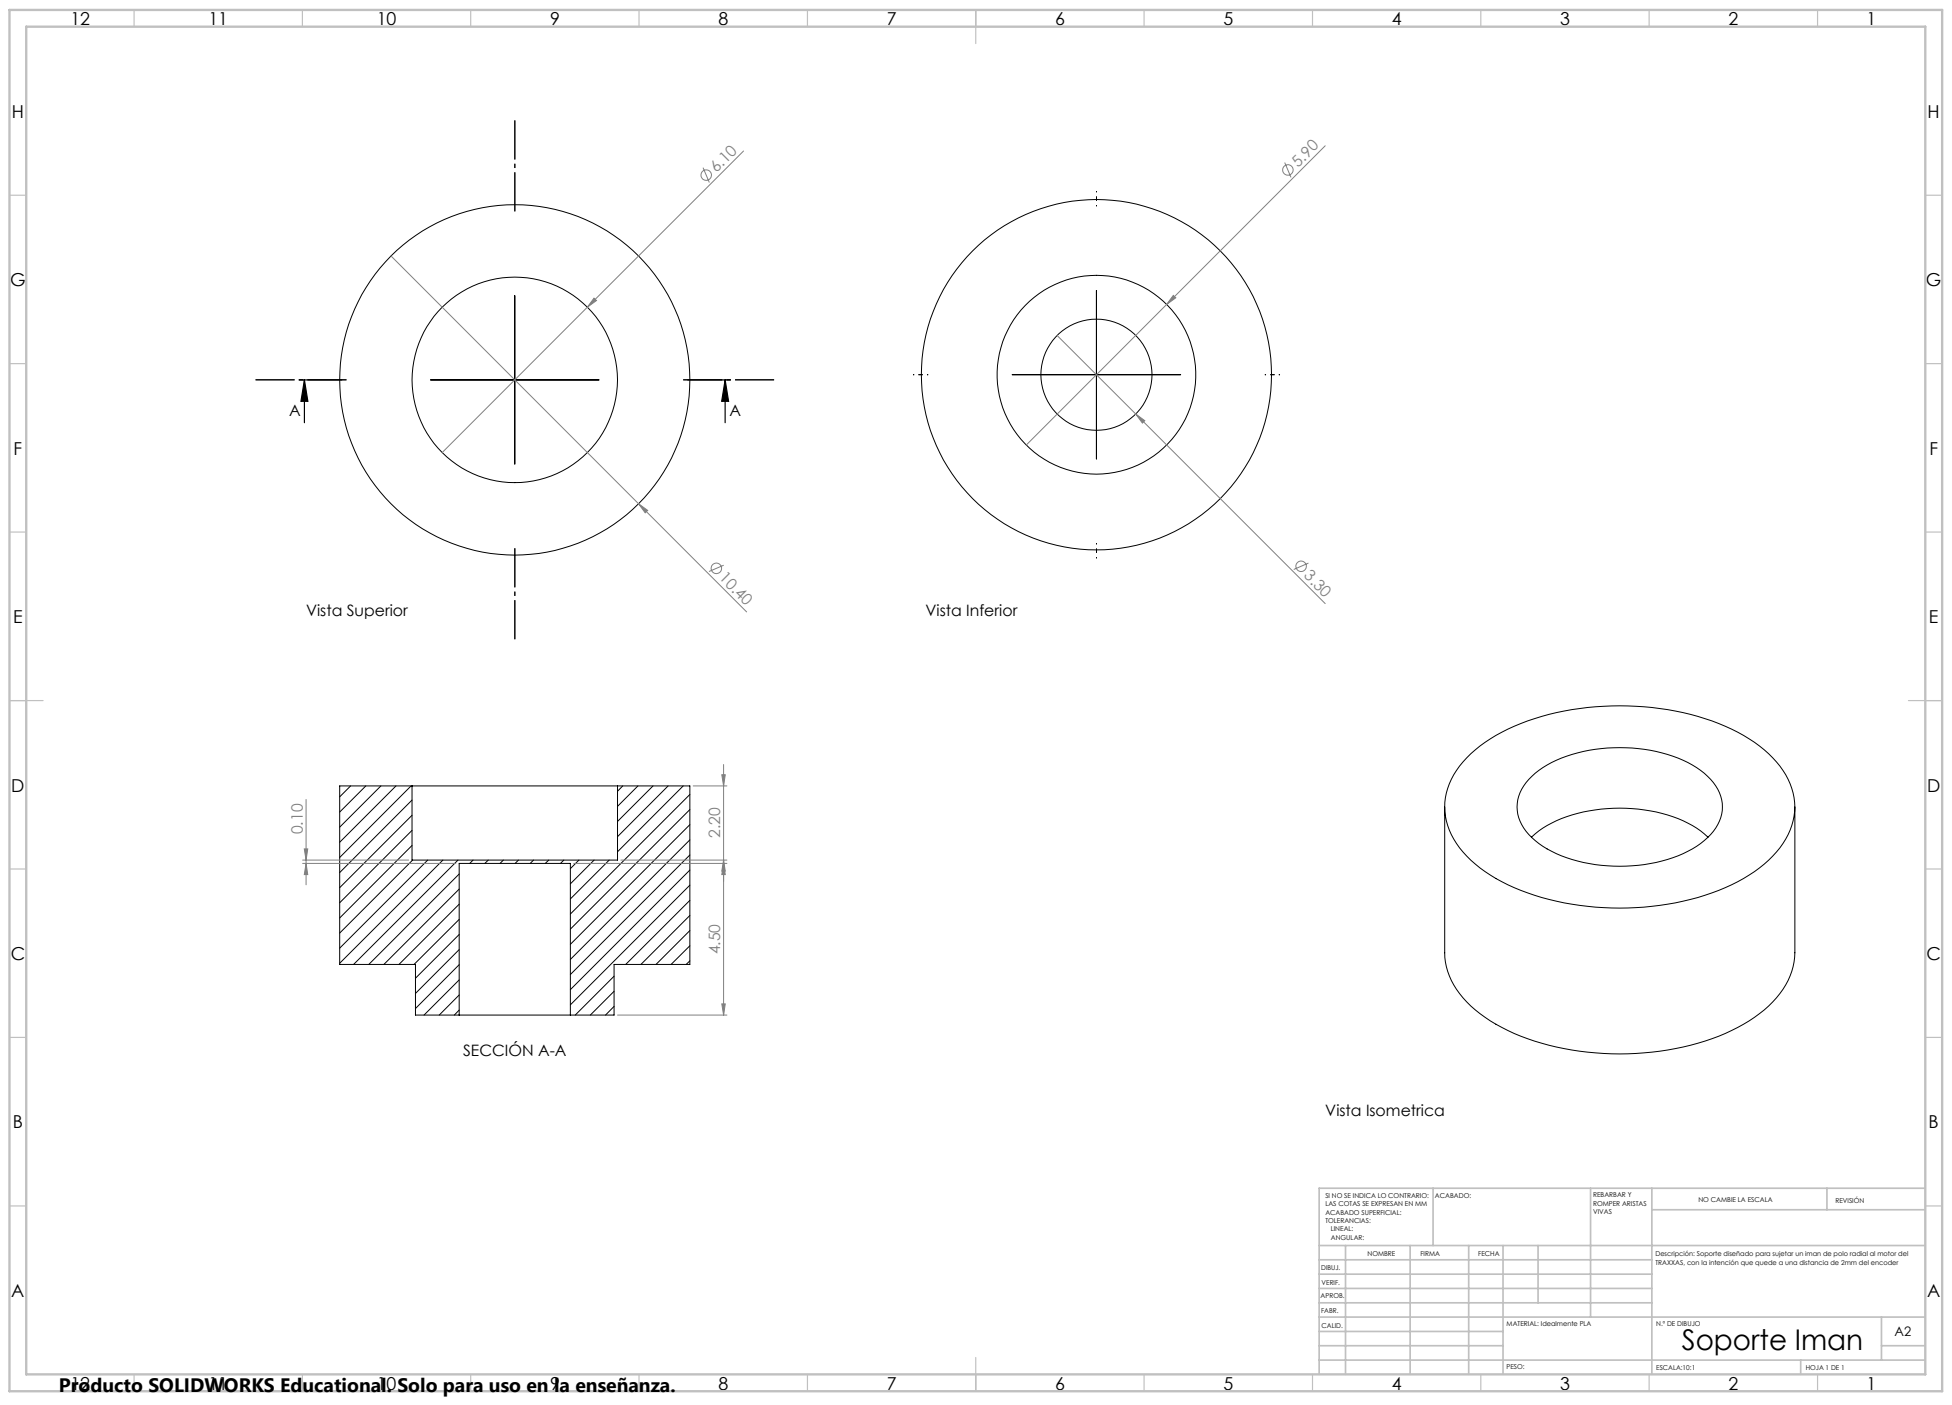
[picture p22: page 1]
SECCIÓN A-A; Vista Superior; Vista Inferior; Vista Isometrica; ESCALA:10:1; HOJA 1 DE 1

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

NOMBRE | FIRMA | FECHA | | | | Descripción: Soporte diseñado para sujetar un iman de polo radial al motor del TRAXXAS, con la intención que quede a una distancia de 2mm del encoder

DIBUJ.
VERIF.
APROB.
FABR.
CALID. | | | | MATERIAL: Idealmente PLA | N.º DE DIBUJO Soporte Iman | A2

Producto SOLIDWORKS Educational. Solo para uso en la enseñanza.

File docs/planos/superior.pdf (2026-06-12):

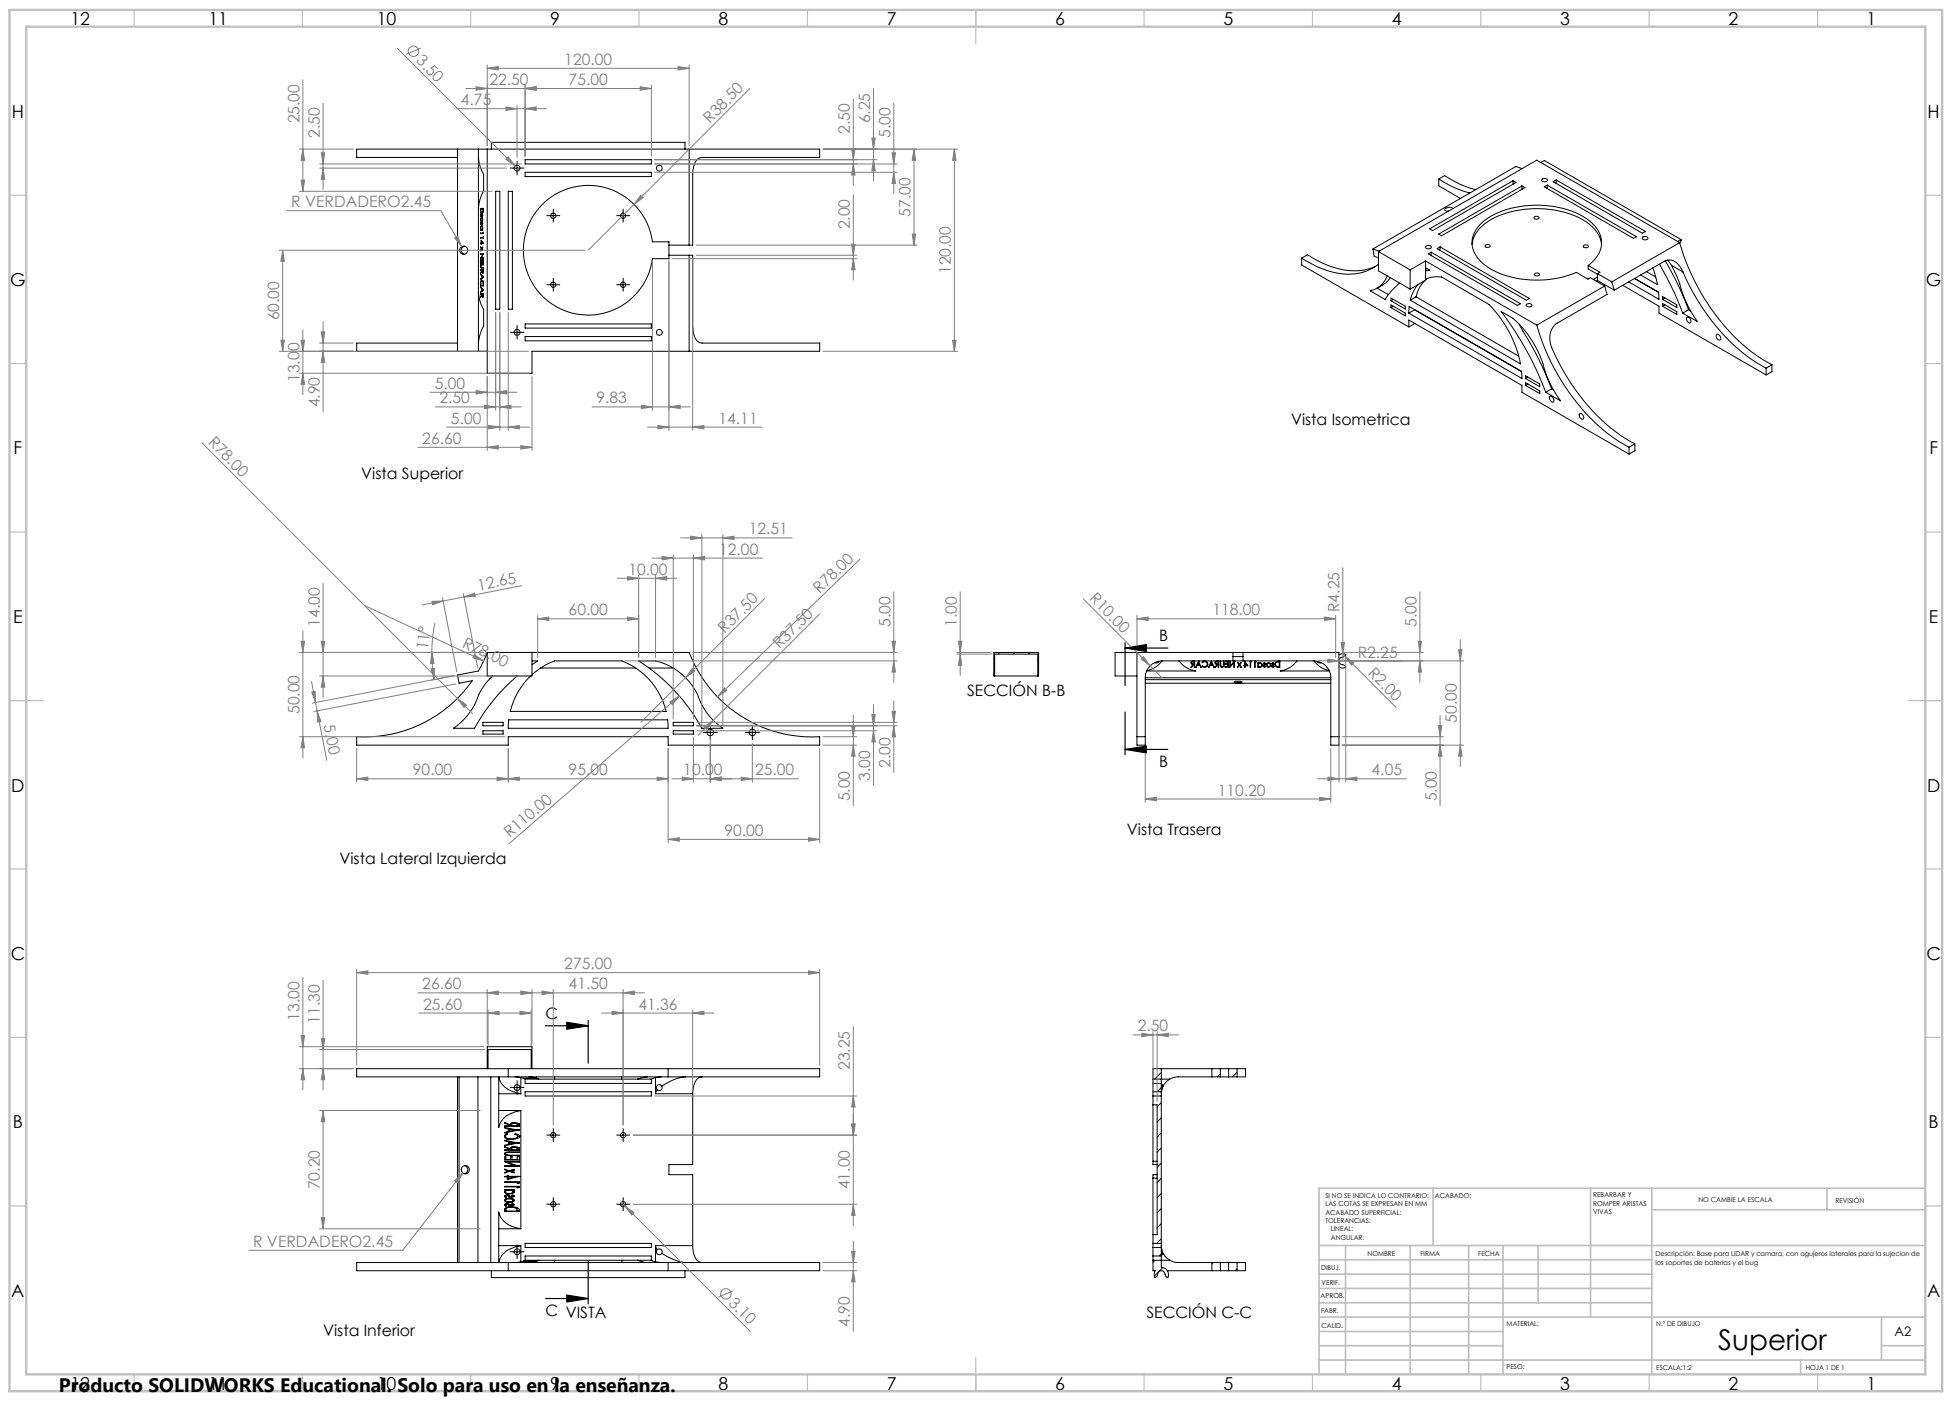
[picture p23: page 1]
R VERDADERO2.45; C VISTA; Vista Inferior; Vista Superior; SECCIÓN B-B; SECCIÓN C-C; Vista Isometrica; Vista Trasera; ACABADO:; REBARBAR Y; ROMPER ARISTAS; NO CAMBIE LA ESCALA; REVISIÓN; ESCALA:1:2; HOJA 1 DE 1

Vista Lateral Izquierda

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

NOMBRE | FIRMA | FECHA | | | | Descripción: Base para LiDAR y camara, con agujeros laterales para la sujecion de los soportes de baterias y el bug

DIBUJ.
VERIF.
APROB.
FABR.
CALID. | | | | MATERIAL: | N.º DE DIBUJO Superior | A2

Producto SOLIDWORKS Educational. Solo para uso en la enseñanza.

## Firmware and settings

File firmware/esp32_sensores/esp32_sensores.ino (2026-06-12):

/**
 * Neuracar — ESP32 SENSORES 
 * ══════════════════════════════════════════════════════════════════
 * Tecnológico de Monterrey, Campus Puebla — MR3002B, 2026
 * Authors: Mariana Manjarrez Lima, Francisco García Uicab
 *
 * Reads AS5047P encoder (SPI init + ABI quadrature runtime) and
 * BNO055 IMU (NDOF fusion mode). Publishes structured telemetry
 * to Jetson Orin Nano via USB-UART at 921600 baud:
 *   E,{angleDeg},{motorRPM},{vLinear}   @ 50 Hz
 *   I,{yaw},{roll},{pitch},{ax},{ay},{az},{gx},{gy},{gz}  @ 50 Hz
 *   STA,{code}  (async, on events)
 *
 * Displays RPM, velocity, angle, IMU orientation, and BNO055
 * calibration status on SSD1306 OLED @ 2 Hz.
 *
 *  PINS
 *  ─────────────────────────────────────────────────────────────────
 *  AS5047P SPI (initial sync):
 *    CS=5   SCK=18   MISO=19   MOSI=23
 *  AS5047P ABI (cuadratura PCNT runtime):
 *    A=32   B=33
 *  OLED SSD1306 128×64: Wire  SDA=21  SCL=22  @0x3C
 *  BNO055:              Wire1 SDA=16  SCL=17  @0x28
 *
 *  PROTOCOL SERIAL @ 921600 baud
 *  ─────────────────────────────────────────────────────────────────
 * ══════════════════════════════════════════════════════════════════
 */

#include <SPI.h>
#include <Wire.h>
#include <ESP32Encoder.h>
#include <Adafruit_GFX.h>
#include <Adafruit_SSD1306.h>
#include <Adafruit_Sensor.h>
#include <Adafruit_BNO055.h>

// ─── PINS ────────────────────────────────────────────────────────
#define CS_PIN      5
#define ENC_A_PIN  32
#define ENC_B_PIN  33

// ─── MECHANICS ───────────────────────────────────────────────────
#define GEAR_RATIO      9.2459f
#define WHEEL_RADIUS_M  0.033f
#define ABI_CPR         4096
#define SPI_RESOLUTION  16384.0f

// ─── HZ ───────────────────────────────────────────────────────────
#define SENSOR_HZ   50
#define OLED_HZ      2

// ─── OLED ─────────────────────────────────────────────────────────
#define SCREEN_W  128
#define SCREEN_H   64
#define OLED_ADDR  0x3C

// ════════════════════════════════════════════════════════════════
//  Objects
// ════════════════════════════════════════════════════════════════

ESP32Encoder     motorEnc;
Adafruit_SSD1306 display(SCREEN_W, SCREEN_H, &Wire, -1);
TwoWire          I2C_IMU = TwoWire(1);
Adafruit_BNO055  bno(55, 0x28, &I2C_IMU);

// ════════════════════════════════════════════════════════════════
//  States
// ════════════════════════════════════════════════════════════════

portMUX_TYPE g_mux = portMUX_INITIALIZER_UNLOCKED;

bool     g_imuOk    = false;
bool     g_oledOk   = false;
bool     g_shutdown = false;

uint32_t g_lastSensorMs = 0;

// Encoder
int64_t  g_encLastCount = 0;
uint32_t g_encLastUs    = 0;
volatile float g_motorRPM = 0.0f;
volatile float g_vLinear  = 0.0f;
volatile float g_angleDeg = 0.0f;

// IMU
volatile float g_yaw=0, g_roll=0, g_pitch=0;
volatile uint8_t g_calSys=0, g_calGyro=0, g_calAccel=0, g_calMag=0;

// TX buffer
static char g_txBuf[160];
#define SERIAL_SEND(fmt, ...) \
    do { snprintf(g_txBuf, sizeof(g_txBuf), fmt, ##__VA_ARGS__); \
         Serial.write((const uint8_t*)g_txBuf, strlen(g_txBuf)); } while(0)

// ════════════════════════════════════════════════════════════════
//  AS5047P — SPI initial sync 
// ════════════════════════════════════════════════════════════════

static uint16_t spi16(uint16_t tx) {
    SPI.beginTransaction(SPISettings(1000000, MSBFIRST, SPI_MODE1));
    digitalWrite(CS_PIN, LOW); delayMicroseconds(1);
    uint16_t hi = SPI.transfer((tx >> 8) & 0xFF);
    uint16_t lo = SPI.transfer(tx & 0xFF);
    delayMicroseconds(1); digitalWrite(CS_PIN, HIGH);
    SPI.endTransaction(); delayMicroseconds(2);
    return (hi << 8) | lo;
}
static uint16_t addParity(uint16_t c) {
    uint16_t p = c & 0x7FFF;
    p ^= p>>8; p ^= p>>4; p ^= p>>2; p ^= p>>1;
    if (p & 1) c |= 0x8000; return c;
}
static uint16_t spiReadAngle() {
    spi16(addParity(0x7FFF));
    return spi16(addParity(0x4000)) & 0x3FFF;
}
static void syncEncoderToAbsolute() {
    uint16_t raw     = spiReadAngle();
    int64_t  initCnt = (int64_t)((float)raw / SPI_RESOLUTION * ABI_CPR);
    motorEnc.setCount(initCnt);
    g_encLastCount = initCnt;
    g_encLastUs    = micros();
    g_angleDeg     = (float)initCnt / ABI_CPR * 360.0f;
    SERIAL_SEND("STA,ENC_SYNC,%.2f\n", raw * 360.0f / SPI_RESOLUTION);
}

// ════════════════════════════════════════════════════════════════
//  Encoder 
// ════════════════════════════════════════════════════════════════

static void readEncoder() {
    int64_t  count = motorEnc.getCount();
    uint32_t nowUs = micros();
    uint32_t dtUs  = nowUs - g_encLastUs;
    if (dtUs < 100) return;
    int64_t delta = count - g_encLastCount;
    float   dtS   = dtUs * 1e-6f;
    float omegaMotor = ((float)delta / ABI_CPR) * TWO_PI / dtS;
    portENTER_CRITICAL(&g_mux);
    g_vLinear  = (omegaMotor / GEAR_RATIO) * WHEEL_RADIUS_M;
    g_motorRPM = omegaMotor * 60.0f / TWO_PI;
    g_angleDeg = (float)count / ABI_CPR * 360.0f;
    portEXIT_CRITICAL(&g_mux);
    g_encLastCount = count;
    g_encLastUs    = nowUs;
}

// ════════════════════════════════════════════════════════════════
//  IMU 
// ════════════════════════════════════════════════════════════════

static void initIMU() {
    g_imuOk = bno.begin();
    if (!g_imuOk) { Serial.write("STA,ERR_IMU\n", 12); return; }
    bno.setExtCrystalUse(true);
    bno.setAxisRemap(Adafruit_BNO055::REMAP_CONFIG_P1);
    bno.setAxisSign(Adafruit_BNO055::REMAP_SIGN_P1);
    delay(50);
    Serial.write("STA,IMU_OK\n", 11);
}

static void readIMU() {
    if (!g_imuOk) return;
    sensors_event_t evOri, evAccel, evGyro;
    bno.getEvent(&evOri,   Adafruit_BNO055::VECTOR_EULER);
    bno.getEvent(&evAccel, Adafruit_BNO055::VECTOR_LINEARACCEL);
    bno.getEvent(&evGyro,  Adafruit_BNO055::VECTOR_GYROSCOPE);
    uint8_t cs=0,cg=0,ca=0,cm=0;
    bno.getCalibration(&cs,&cg,&ca,&cm);
    portENTER_CRITICAL(&g_mux);
    g_yaw=evOri.orientation.x; g_roll=evOri.orientation.y; g_pitch=evOri.orientation.z;
    g_calSys=cs; g_calGyro=cg; g_calAccel=ca; g_calMag=cm;
    portEXIT_CRITICAL(&g_mux);
    SERIAL_SEND("I,%.2f,%.2f,%.2f,%.4f,%.4f,%.4f,%.4f,%.4f,%.4f\n",
        evOri.orientation.x, evOri.orientation.y, evOri.orientation.z,
        evAccel.acceleration.x, evAccel.acceleration.y, evAccel.acceleration.z,
        evGyro.gyro.x, evGyro.gyro.y, evGyro.gyro.z);
}

// ════════════════════════════════════════════════════════════════
//  OLED 
//
//  128×64 px, text size 1 (6×8 px/char), refresh rate @ 2 Hz
//
//  Y=0  "Neuracar  SENSORES" 
//  Y=14  RPM motor + wheel linear speed
//  Y=26  Encoder absolute angle
//  Y=38  Yaw / Roll / Pitch  (o "IMU: ERROR")
//  Y=52  BNO055  S/G/A/M  (0–3) calibration
//        If SHUTDOWN → "    APAGANDO...    "
// ════════════════════════════════════════════════════════════════

static void oledTask(void* pv) {
    const TickType_t xDelay = pdMS_TO_TICKS(1000 / OLED_HZ);
    char buf[22];
    for (;;) {
        vTaskDelay(xDelay);
        if (!g_oledOk) continue;

        portENTER_CRITICAL(&g_mux);
        float rpm=g_motorRPM, vl=g_vLinear, ang=g_angleDeg;
        float yaw=g_yaw, roll=g_roll, pitch=g_pitch;
        bool imuOk=g_imuOk, sd=g_shutdown;
        uint8_t cs=g_calSys, cg=g_calGyro, ca=g_calAccel, cm=g_calMag;
        portEXIT_CRITICAL(&g_mux);

        display.clearDisplay();
        display.setTextColor(SSD1306_WHITE);
        display.setTextSize(1);

        display.setCursor(0, 0);
        display.print("Neuracar  SENSORES");
        display.drawLine(0, 9, 127, 9, SSD1306_WHITE);

        display.setCursor(0, 14);
        snprintf(buf, sizeof(buf), "RPM:%+.0f V:%+.2fm/s", rpm, vl);
        display.print(buf);

        display.setCursor(0, 26);
        snprintf(buf, sizeof(buf), "Ang: %.1f deg", ang);
        display.print(buf);

        display.setCursor(0, 38);
        if (imuOk) {
            snprintf(buf, sizeof(buf), "Y:%3.0f R:%+.0f P:%+.0f", yaw, roll, pitch);
            display.print(buf);
        } else { display.print("IMU: ERROR"); }

        display.setCursor(0, 52);
        if (sd) {
            display.setTextColor(SSD1306_BLACK, SSD1306_WHITE);
            display.print("    APAGANDO...     ");
            display.setTextColor(SSD1306_WHITE);
        } else {
            snprintf(buf, sizeof(buf), "CAL: S%d G%d A%d M%d", cs, cg, ca, cm);
            display.print(buf);
        }

        display.display();   
    }
}

// ════════════════════════════════════════════════════════════════
//  Serial Parser
// ════════════════════════════════════════════════════════════════

static char    g_rxBuf[32];
static uint8_t g_rxIdx = 0;

static void readSerial() {
    while (Serial.available()) {
        char c = (char)Serial.read();
        if (c == '\n') {
            g_rxBuf[g_rxIdx] = '\0';
            if (strncmp(g_rxBuf, "SHUTDOWN", 8) == 0) {
                portENTER_CRITICAL(&g_mux);
                g_shutdown = true;
                portEXIT_CRITICAL(&g_mux);
                Serial.write("STA,SHUTDOWN_ACK\n", 17);
            }
            g_rxIdx = 0;
        } else if (c != '\r' && g_rxIdx < sizeof(g_rxBuf)-1) {
            g_rxBuf[g_rxIdx++] = c;
        } else if (g_rxIdx >= sizeof(g_rxBuf)-1) {
            g_rxIdx = 0;
        }
    }
}

// ════════════════════════════════════════════════════════════════
//  SETUP
// ════════════════════════════════════════════════════════════════

void setup() {
    Serial.setTxBufferSize(4096);
    Serial.setRxBufferSize(512);
    Serial.begin(921600);
    delay(100);

    pinMode(CS_PIN, OUTPUT);
    digitalWrite(CS_PIN, HIGH);
    SPI.begin(18, 19, 23, CS_PIN);
    delay(100);

    Wire.begin(21, 22);    Wire.setClock(400000);    
    I2C_IMU.begin(16, 17); I2C_IMU.setClock(400000); 

    g_oledOk = display.begin(SSD1306_SWITCHCAPVCC, OLED_ADDR);
    if (g_oledOk) {
        display.clearDisplay(); display.setTextSize(1);
        display.setTextColor(SSD1306_WHITE);
        display.setCursor(0,0);  display.print("Neuracar  SENSORES");
        display.drawLine(0,9,127,9,SSD1306_WHITE);
        display.setCursor(0,14); display.print("Iniciando...");
        display.display();
    } else {
        Serial.write("STA,WARN_OLED_NOT_FOUND\n", 24);
    }

    initIMU();

    ESP32Encoder::useInternalWeakPullResistors = puType::up;
    motorEnc.attachFullQuad(ENC_A_PIN, ENC_B_PIN);
    motorEnc.setCount(0);
    delay(50);
    syncEncoderToAbsolute();

    xTaskCreatePinnedToCore(oledTask, "OLED", 4096, NULL, 1, NULL, 0);

    g_lastSensorMs = millis();

    Serial.write("STA,READY_SENSORES\n", 19);
}

// ════════════════════════════════════════════════════════════════
//  LOOP 
// ════════════════════════════════════════════════════════════════

void loop() {
    uint32_t now = millis();

    readSerial();

    if (g_shutdown) return;

    if (now - g_lastSensorMs >= (1000U / SENSOR_HZ)) {
        g_lastSensorMs = now;
        readEncoder();
        SERIAL_SEND("E,%.2f,%.2f,%.4f\n", g_angleDeg, g_motorRPM, g_vLinear);
        readIMU();
    }
}

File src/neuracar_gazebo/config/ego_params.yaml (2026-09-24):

/**:
  ros__parameters:
    # Body params
    body_length: 0.425 # Length of the vehicle's body [m]
    body_width: 0.192 # Width of the vehicle's body [m]
    body_height: 0.182 # Height of the vehicle's body [m]
    body_mass: 2.552 # Mass of the vehicle's body [kg]
    wheel_base: 0.256 # Distance between front and rear axles [m]
    track_width: 0.172 # Distance between left and right wheels [m]

    # Wheel params
    wheel_radius: 0.033 # Radius of each wheel [m]
    wheel_width: 0.025 # Width of each wheel [m]
    wheel_mass: 0.035 # Mass of the wheel material [kg]

    # Kinematics and dynamics params
    max_steering_angle: 0.523 # Maximum steering angle of the vehicle [rad]
    max_steering_angular_velocity: 1.570796 # Maximum steering angular velocity [rad/s]
    max_steering_effort: 1.0 # Maximum steering torque [Nm]
    max_velocity: 0.4458883 # Maximum wheel velocity [m/s]
    max_effort: 0.5649 #5.12766 # Maximum wheel torque [Nm]

    #Publish topic
    publish_topic: /neuracar/user_command

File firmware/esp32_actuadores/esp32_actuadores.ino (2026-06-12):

/**
 * Neuracar — ESP32 ACTUADORES  
 * ══════════════════════════════════════════════════════════════════
 * Tecnológico de Monterrey, Campus Puebla — MR3002B, 2026
 * Authors: Mariana Manjarrez Lima, Maximiliano Cruz Rascón
 *
 * Receives C,{throttle},{steering} frames from Jetson via
 * USB-UART at 921600 baud and generates 50 Hz PWM signals
 * for Traxxas XL-5 ESC and steering servo.
 * Implements latest-only TX pattern and 500 ms watchdog.
 *
 *  PINS
 *  ─────────────────────────────────────────────────────────────────
 *  ESC signal:    GPIO 25
 *  Servo signal:  GPIO 26
 *  Common GND with ESP32-S, ESC and Servo
 *
 *  PROTOCOL SERIAL @ 921600 baud
 *  ─────────────────────────────────────────────────────────────────
 * ══════════════════════════════════════════════════════════════════
 */

#include <ESP32Servo.h>

// ─── PINES ────────────────────────────────────────────────────────
#define ESC_PIN    25
#define SERVO_PIN  26

// ─── ESC / SERVO   ────────────────────────────────────────────────
#define ESC_NEUTRAL   1512
#define ESC_FORWARD   1750
#define ESC_REVERSE   1274
#define SERVO_CENTER  1549
#define SERVO_LEFT    1101 // 448
#define SERVO_RIGHT   1997 // 448

// ════════════════════════════════════════════════════════════════
//  Objects
// ════════════════════════════════════════════════════════════════

Servo esc;
Servo steeringServo;

// ════════════════════════════════════════════════════════════════
//  States
// ════════════════════════════════════════════════════════════════

float g_throttle = 0.0f;
float g_steering = 0.0f;
bool  g_estop    = false;
bool  g_shutdown = false;

static char g_txBuf[64];
#define SERIAL_SEND(fmt, ...) \
    do { snprintf(g_txBuf, sizeof(g_txBuf), fmt, ##__VA_ARGS__); \
         Serial.write((const uint8_t*)g_txBuf, strlen(g_txBuf)); } while(0)

// ════════════════════════════════════════════════════════════════
//  Actuators
// ════════════════════════════════════════════════════════════════

static int normalizedToPwm(float v, int pwmMin, int pwmNeutral, int pwmMax) {
    v = constrain(v, -1.0f, 1.0f);
    return (v >= 0.0f)
        ? pwmNeutral + (int)((float)(pwmMax - pwmNeutral) * v)
        : pwmNeutral + (int)((float)(pwmNeutral - pwmMin) * v);
}

static void neutralActuators() {
    esc.writeMicroseconds(ESC_NEUTRAL);
    steeringServo.writeMicroseconds(SERVO_CENTER);
    g_throttle = 0.0f;
    g_steering = 0.0f;
}

static void applyCommands(float throttle, float steering) {
    if (g_estop || g_shutdown) return;
    esc.writeMicroseconds(constrain(
        normalizedToPwm(throttle, ESC_REVERSE, ESC_NEUTRAL, ESC_FORWARD),
        ESC_REVERSE, ESC_FORWARD));
    steeringServo.writeMicroseconds(constrain(
        normalizedToPwm(steering, SERVO_LEFT, SERVO_CENTER, SERVO_RIGHT),
        SERVO_LEFT, SERVO_RIGHT));
}

// ════════════════════════════════════════════════════════════════
//  Serial Parser
// ════════════════════════════════════════════════════════════════

static char    g_rxBuf[64];
static uint8_t g_rxIdx = 0;

static void parseLine(char* line) {
    if (line[0] == 'C' && line[1] == ',') {
        float t = 0.0f, s = 0.0f;
        if (sscanf(line + 2, "%f,%f", &t, &s) == 2) {
            g_throttle = constrain(t, -1.0f, 1.0f);
            g_steering = constrain(s, -1.0f, 1.0f);
            applyCommands(g_throttle, g_steering);
        }
        return;
    }

    if (strncmp(line, "SHUTDOWN", 8) == 0) {
        g_shutdown = true;
        neutralActuators();
        Serial.write("STA,SHUTDOWN_ACK\n", 17);
        return;
    }

    if (strncmp(line, "CLRESTOP", 8) == 0) {
        g_estop = false;
        Serial.write("STA,ESTOP_CLEAR\n", 16);
        return;
    }

}

static void readSerial() {
    while (Serial.available()) {
        char c = (char)Serial.read();
        if (c == '\n') {
            g_rxBuf[g_rxIdx] = '\0';
            if (g_rxIdx > 0) parseLine(g_rxBuf);
            g_rxIdx = 0;
        } else if (c != '\r' && g_rxIdx < sizeof(g_rxBuf) - 1) {
            g_rxBuf[g_rxIdx++] = c;
        } else if (g_rxIdx >= sizeof(g_rxBuf) - 1) {
            g_rxIdx = 0; 
        }
    }
}

// ════════════════════════════════════════════════════════════════
//  SETUP
// ════════════════════════════════════════════════════════════════

void setup() {
    Serial.setRxBufferSize(2048);
    Serial.setTxBufferSize(256);
    Serial.begin(921600);
    delay(100);

    esc.attach(ESC_PIN, 1000, 2000);
    steeringServo.attach(SERVO_PIN, 1000, 2000);
    neutralActuators();

    delay(2000);

    Serial.write("STA,READY_ACTUADORES\n", 21);
}

// ════════════════════════════════════════════════════════════════
//  LOOP
// ════════════════════════════════════════════════════════════════

void loop() {
    readSerial();
}

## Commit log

2026-04-22 Primer commit: estructura inicial de paquetes ROS 2 y configuración de Git
2026-04-24 Segundo commit: Actualizando cambios y eliminando submódulos de LiDAR y Cámara no deseados dentro de GitHub, creación launch de lanzamiento de 2 sensores
2026-04-28 Commit 3: actualizado .gitignore para ignorar los submódulos realsense-ros y rplidar_ros, nodos para usar el contro remoto con tópicos
2026-05-13 Commit 4: modificación de nodos para el cotrol remoto
2026-05-22 Commit 5: Actualización del archivo de lanzamiento de sensores
    Se agregaron argumentos configurables de lanzamiento para la cámara, el LiDAR y Teensy. Y se actualizaron las definiciones de nodos para incluir condiciones basadas en los argumentos.
2026-05-22 Commit 6: Implementa nodo puente Teensy-ROS2 y agrega soporte para protocolo de apagado
2026-06-01 Commit 7: incorporación de un nuevo paquete ROS 2 para percepción, incluyendo nodos de LiDAR y odometría, junto con las modificaciones necesarias para trasladar al ESP32 las funciones que anteriormen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
2026-06-01 Commit 7.1: Corrección de errores en el firmware del ESP32
2026-06-01 Commit 8: controlador Stanley, detector de carriles y actualización de launch
2026-06-02 Commit 9: Integra dashboard en tiempo real y optimiza percepción, detección y seguimiento de trayectoria
2026-06-02 Commit 9.1: actualizar esp32 actuadores
2026-06-02 Commit 9.2: actualizar esp32 actuadores
2026-06-02 Commit 9.3: actualizar esp32 actuadores y sensores en 2 nodos y launch que lo considera
2026-06-02 Commit 9.4: actualizar nombre en launch sensores
2026-06-02 Commit 9.5: actualizar nombre en esp32 sensores
2026-06-02 Commit 9.6: actualizar esp32 actuadores
2026-06-02 Commit 9.7: actualizar esp32 actuadores
2026-06-03 Commit 10: mejoras en odometría e integración de sensores ESP32
2026-06-03 Commit 11: actualización del nodo LiDAR para la detección de obstáculos frontales
2026-06-04 Commit 12: actualizar launch de sensores para revisar la cámara
2026-06-04 Commit 13: refactorización de los nodos Stanley y grabador de trayectoria para un manejo consistente de las salidas
2026-06-04 Commit 13.1: actualización de los nodos Stanley y grabador de trayectoria
2026-06-04 Commit 14: actualización del nodo de odometría para garantizar la compatibilidad con el controlador Stanley
2026-06-05 Commit 15: actualización del nodo del grabador de trayectoria y creación de nodo de pure pursuit
2026-06-05 Commit 16: refactorización de control y percepción con soporte para PID de velocidad, control remoto y mejoras en Stanley, Pure Pursuit y detección de obstáculos
2026-06-05 Commit 16.1: refactorización de control y y dashboard para PID de velocidad
2026-06-07 Commit 17: Mejoras en Pure Pursuit, PID de velocidad y detección de obstáculos
    [track_20260603_113420.csv, track_20260603_113551.csv, track_20260603_141035.csv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]
2026-06-07 Commit 18: Ajustes en grabación de trayectorias, Pure Pursuit y Stanley
    [vuelta_01_20260603_205522_analysis.csv, vuelta_01_20260603_211936_analysis.csv, vuelta_01_20260603_212133_analysis.csv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]
2026-06-08 Commit 19: Comparación entre Pure Pursuit y Stanley con nuevos resultados de seguimiento
    [vuelta_05_5cm_20260607_163626_stanley_analysis.csv, vuelta_05_5cm_20260607_183918_stanley_analysis.csv, vuelta_05_5cm_20260607_184130_stanley_analysis.csv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]
2026-06-08 Commit 20: Actualización de resultados Pure Pursuit y Stanley
    [vuelta_01_20260603_205522_analysis.csv, vuelta_01_20260603_211936_analysis.csv, vuelta_01_20260603_212133_analysis.csv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]
2026-06-08 Commit 20.1: Archivos de calibración
    [lut_recta_20260606_195248.csv, lut_recta_20260606_195640.csv, lut_recta_20260606_200250.csv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]
2026-06-09 Commit 21: Eliminar utilidades de ajuste PID y actualizar configuración de lanzamiento
    [lut_recta_20260606_195248.csv, lut_recta_20260606_195640.csv, lut_recta_20260606_200250.csv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]
2026-06-09 Commit 22: Actualizar configuración de lanzamiento
2026-06-09 Commit 22.1: Actualizar configuración de lanzamiento
2026-06-12 Commit 23: Integración final, depuración y estandarización del proyecto
    - Se agregan modelos CAD, planos y archivos de manufactura
    - Se incorpora el firmware final para ESP32 de sensores y actuadores
    - Se añade la documentación, reportes y renders finales
    - Se refactorizan y formatean paquetes y archivos launch de ROS 2
    - Se mejoran nodos de percepción, control y sensores
    - Se eliminan trayectorias y datos experimentales obsoletos
    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
    [Acrilico.SLDDRW, NCD tornillos.SLDPRT, Soporte Encoder.SLDDRW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]
2026-06-12 Commit 23.1: Reorganización y renombrado de archivos mecánicos y documentación
    [base PLA.SLDPRT, base PLA.STL, base acrilico.SLDPRT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]
2026-09-18 added: new description and gazebo preliminary packages
    [Lidar_A3.stl, SteeringHubL.stl, SteeringHubR.stl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]

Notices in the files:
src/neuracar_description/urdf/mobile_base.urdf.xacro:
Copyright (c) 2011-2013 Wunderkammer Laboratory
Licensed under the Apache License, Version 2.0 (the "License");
